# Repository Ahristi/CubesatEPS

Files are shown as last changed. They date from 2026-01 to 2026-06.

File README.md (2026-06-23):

# CubeSat EPS

Electrical Power System (EPS) hardware and firmware for a Docker-1 Cubesat. The project contains Altium projects and embedded firmware for the two EPS PCBs: The Battery Management System (BMS) and the Power Distribution Module (PDM).
<table>
  <tr>
    <td align="center">
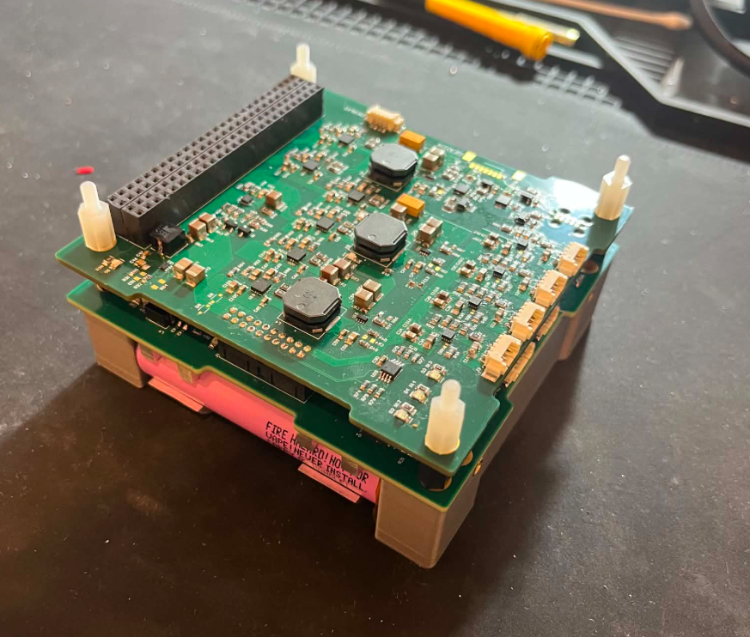
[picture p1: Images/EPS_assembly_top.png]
EPS Assembly top view
      <br>
      <b>EPS Assembly top view</b>
    </td>
    <td align="center">
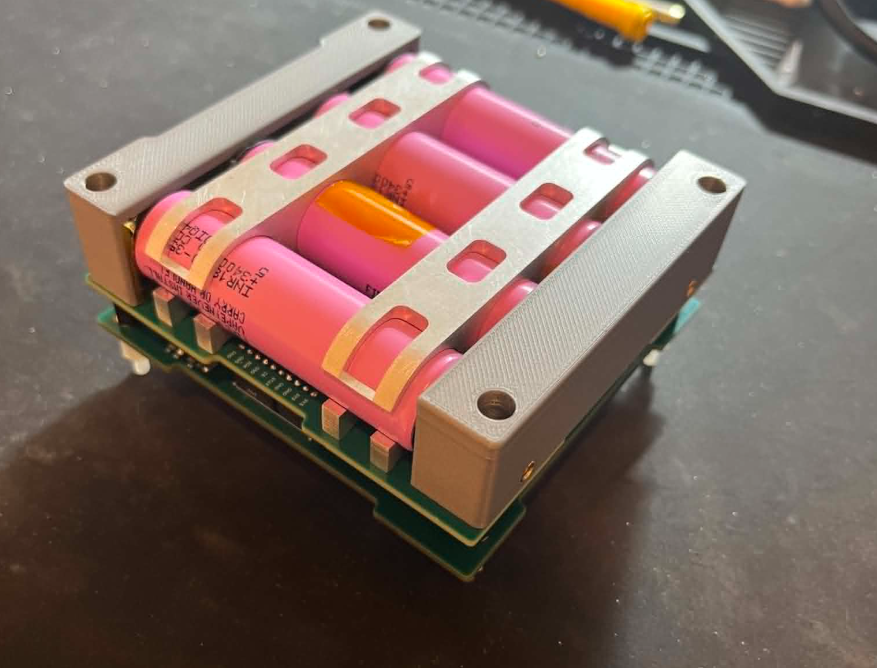
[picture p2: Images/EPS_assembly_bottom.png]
EPS Assembly bottom view
      <br>
      <b>EPS Assembly bottom view</b>
    </td>
  </tr>
</table>

## Overview
The EPS is comprised of two boards:
- **BMS — Battery Management System**: Contains a 4S Li-Ion battery directly soldered to the PCB. Performs battery protection, battery seperation, umbilical charging and solar panel charging via two MPPT boost circuits.
<table>
  <tr>
    <td align="center">
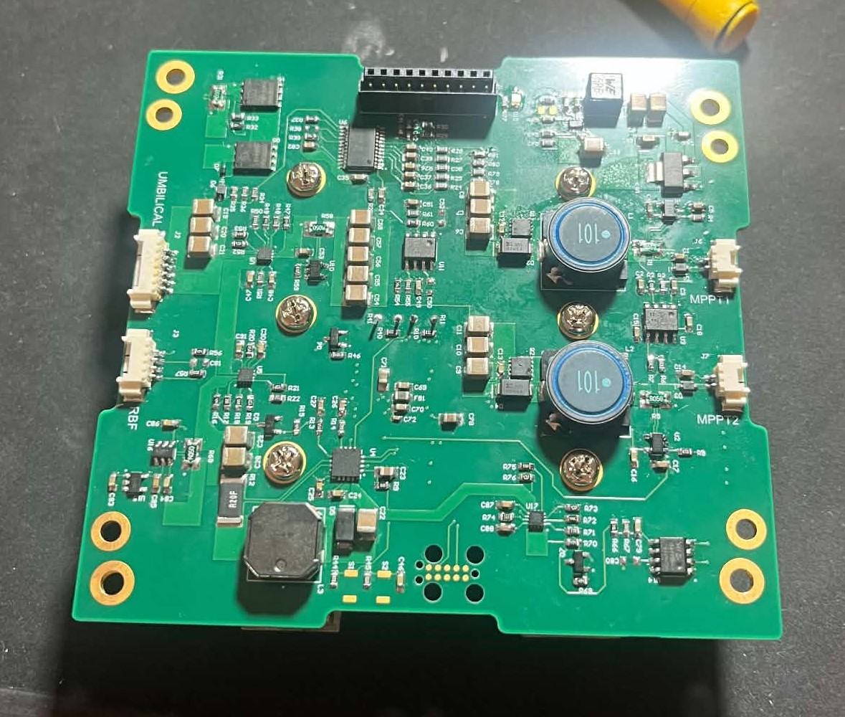
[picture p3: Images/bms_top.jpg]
BMS PCB top view
      <br>
      <b>BMS PCB</b>
    </td>
    <td align="center">
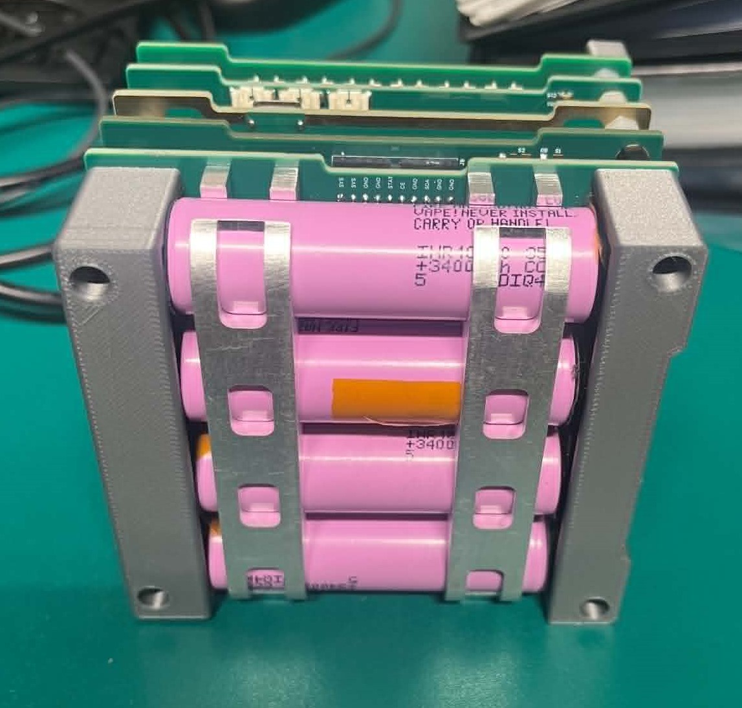
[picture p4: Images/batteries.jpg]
Bottom of BMS showing battery mounting
      <br>
      <b>Battery Pack</b>
    </td>
  </tr>
</table>

- **PDM — Power Distribution Module**: Regulates the raw battery voltage from the BMS to the voltages required by other subsystems on the satellite.
<table>
  <tr>
    <td align="center">
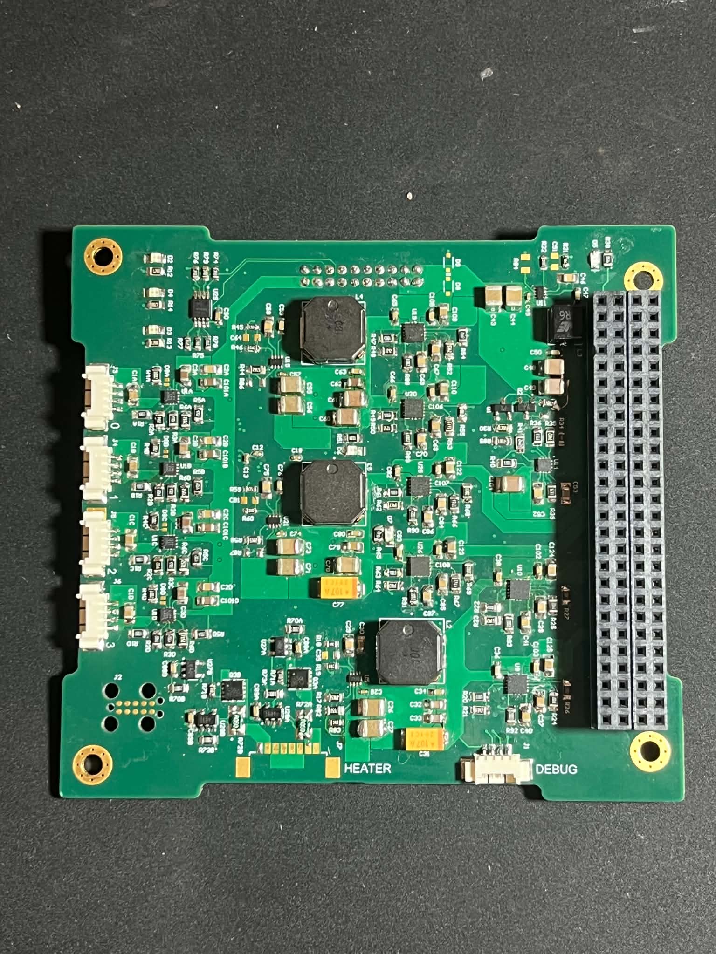
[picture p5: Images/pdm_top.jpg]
PDM PCB top view
      <br>
      <b>BMS PCB</b>
    </td>
    <td align="center">
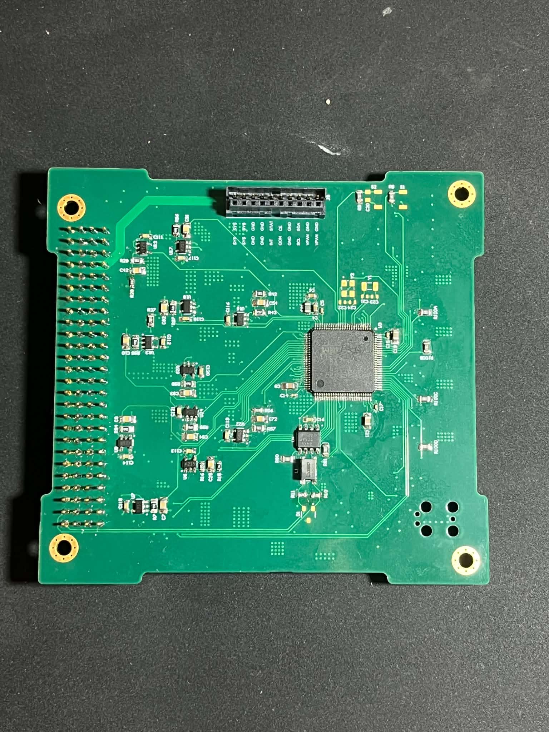
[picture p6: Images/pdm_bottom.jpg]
PDM PCB bottom view
      <br>
      <b>Battery Pack</b>
    </td>
  </tr>
</table>

The firmware for the PDM is an STM32 eclipse project. With code generated using HAL libraries from CubeMX. The firmware for the BMS is a platformIO project, with code also generated from STM32CubeMX

## Repository Structure

```text
CubesatEPS/
├── CAD/                  # Mechanical/CAD assets
├── Software/             # Firmware and Python support tools
│   ├── BMS/              # STM32 BMS firmware project
│   ├── BMS_Test/         # BMS test firmware/software
│   ├── PDM/              # PDM firmware, CAN tools, telemetry scripts
│       ├──  PDM/         # STM32 project for PDM
|       └──  EPS_gui.py   # Python script used to monitor EPS CAN telemetry and turn eFuses on/off.
├── hardware/             # PCB design files
│   ├── BMS/              # BMS Altium hardware project files
│   └── PDM/              # PDM Altium hardware project files
└── .gitignore
```

## Main Features

### Battery Management System

- Battery protection and power-path control
- Solar input regulation and MPPT control
- Umbilical charging interface
- ADC-based telemetry acquisition
- STM32Cube/PlatformIO firmware project
- ST-Link upload and debug support

### Power Distribution Module

- Regulated spacecraft power rails
- Protected load switching/eFuse control
- Voltage and current telemetry
- CAN-based command and telemetry interface
- Python tools for listening to, decoding, and plotting EPS telemetry

### Software Tooling

- STM32Cube-generated firmware structure
- PlatformIO build support for the BMS firmware
- Python CAN controller/listener utilities
- JSON-based command and conversion definitions
- Live plotting scripts for power rail current testing

## Hardware

The hardware design files are stored under:

```text
hardware/BMS/
hardware/PDM/
```

These folders contain the Altium projects for battery management and power distribution boards.
## Known Issues
- Battery current measurement is a quite poor. This is because the current measurement instrumentation amplifier is backfeeding current to the 1.5V reference which causes the reference to rise to about 2.4V. This needs to be fixed by adding a lower output impedance bbuffer ont he output of the LDO.
- PDM 6V enable MOSFET circuit is incorrect. R33 should be pulled directly to 5V5. This was fixed by a small rework on the board, but should be fixed in the next revision.
- Legacy GPIOs on the mezzanine connector which do nothing currently. This were to ensure backwards compatibility with old V1 hardware but aren't used anymore.
- Heater driver is currently untested as we didn't use it in the end for the DOCKER-1 project.

## Future improvements
- I2C is a bit finnicky for the PDM to BMS link. In a future revision I would probably change it to be directly on the CANbus.
- Ideal diodes on the PDM are legacy hardware that are unused as MPPT is done directly on the BMS. Previously on the V1 of the BMS, the BMS contained a single MPPT circuit and these ideal diodes would output whichever panel was the most illuminated.
- Change the buck converter ICs from TPS6993 to AP64501. I was planning on doing this in a second revision of the PDM but unfortunately ran out of time since I had 5 other PCBs to design for the satellite.
- If you have to do one thing I beg you to replace all the PDM efuses with TPS25497. The TPS16410 that I used for all the PDM outputs (except for the 6V output) is a piece of shit and really hard to solder. The TPS25947 is marginally more expensive, but has a higher current rating and reverse current blocking. We had some issues plugging USBs into boards downstream using the TPS16410. The TPS25947 is much easier to solder as well from my experience.

## Author

Developed by Tom Holland / Ahristi as part of the DOCKER-1 project for AERO4701 at the University of Sydney

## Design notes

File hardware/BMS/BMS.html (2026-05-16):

Altium customize

# Board Information Report

Date: | | 16/05/2026
Time: | | 10:33:02 AM
Elapsed Time: | | 00:00:00
Filename: | | C:\Users\Tom\Documents\CubesatEPS\hardware\BMS\BMS.PcbDoc

## Contents

Contents

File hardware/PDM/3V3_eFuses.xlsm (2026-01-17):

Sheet: TPS1641x_Calculation Sheet
TPS1641x Design Calculation Tool |  |  |  |  |  |  |  |  | Table - 1: Device Comparison Table
Constants Cells | Input/SelectCells | Calculation Cells |  |  | Recommended |  |  |  | TPS16410 | PLIM | Auto-Retry
Error Cells, Must be Fixed | Calculated, but can be over-ridden by user |  |  |  | Value |  |  |  | TPS16411 | PLIM | Latch-Off
Parameter | Description | Value | Units | Tolerance |  |  |  |  | TPS16412 | ILIM | Auto-Retry
Device Selection | Refer Table-1 and select device based on current or power limiting requirement and fault behavior (auto-retry or latchoff) | TPS16416 |  |  |  |  |  |  | TPS16413 | ILIM | Latch-Off
VIN (nom) | Nominal operating input voltage | 3.30 | V |  |  |  |  |  | TPS16414 | PLIM | Auto-Retry
Cout | Load Capacitance | 100.00 | uF | 10.0% |  |  |  |  | TPS16415 | PLIM | Latch-Off
Iout | Maximum load current | 0.50 | A |  |  |  |  |  | TPS16416 | ILIM | Auto-Retry
Icharge_req | Charging (inrush) current desired in the system | 0.20 | A |  |  |  |  |  | TPS16417 | ILIM | Latch-Off
ILIM | Current limit threshold for active current limiting | 0.70 | A
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

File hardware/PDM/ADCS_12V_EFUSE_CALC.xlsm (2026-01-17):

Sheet: TPS1641x_Calculation Sheet
TPS1641x Design Calculation Tool |  |  |  |  |  |  |  |  | Table - 1: Device Comparison Table
Constants Cells | Input/SelectCells | Calculation Cells |  |  | Recommended |  |  |  | TPS16410 | PLIM | Auto-Retry
Error Cells, Must be Fixed | Calculated, but can be over-ridden by user |  |  |  | Value |  |  |  | TPS16411 | PLIM | Latch-Off
Parameter | Description | Value | Units | Tolerance |  |  |  |  | TPS16412 | ILIM | Auto-Retry
Device Selection | Refer Table-1 and select device based on current or power limiting requirement and fault behavior (auto-retry or latchoff) | TPS16416 |  |  |  |  |  |  | TPS16413 | ILIM | Latch-Off
VIN (nom) | Nominal operating input voltage | 12.00 | V |  |  |  |  |  | TPS16414 | PLIM | Auto-Retry
Cout | Load Capacitance | 100.00 | uF | 10.0% |  |  |  |  | TPS16415 | PLIM | Latch-Off
Iout | Maximum load current | 1.40 | A |  |  |  |  |  | TPS16416 | ILIM | Auto-Retry
Icharge_req | Charging (inrush) current desired in the system | 0.20 | A |  |  |  |  |  | TPS16417 | ILIM | Latch-Off
ILIM | Current limit threshold for active current limiting | 1.60 | A
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

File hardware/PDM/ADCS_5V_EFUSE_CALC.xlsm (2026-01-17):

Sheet: TPS1641x_Calculation Sheet
TPS1641x Design Calculation Tool |  |  |  |  |  |  |  |  | Table - 1: Device Comparison Table
Constants Cells | Input/SelectCells | Calculation Cells |  |  | Recommended |  |  |  | TPS16410 | PLIM | Auto-Retry
Error Cells, Must be Fixed | Calculated, but can be over-ridden by user |  |  |  | Value |  |  |  | TPS16411 | PLIM | Latch-Off
Parameter | Description | Value | Units | Tolerance |  |  |  |  | TPS16412 | ILIM | Auto-Retry
Device Selection | Refer Table-1 and select device based on current or power limiting requirement and fault behavior (auto-retry or latchoff) | TPS16416 |  |  |  |  |  |  | TPS16413 | ILIM | Latch-Off
VIN (nom) | Nominal operating input voltage | 5.00 | V |  |  |  |  |  | TPS16414 | PLIM | Auto-Retry
Cout | Load Capacitance | 100.00 | uF | 10.0% |  |  |  |  | TPS16415 | PLIM | Latch-Off
Iout | Maximum load current | 0.50 | A |  |  |  |  |  | TPS16416 | ILIM | Auto-Retry
Icharge_req | Charging (inrush) current desired in the system | 0.20 | A |  |  |  |  |  | TPS16417 | ILIM | Latch-Off
ILIM | Current limit threshold for active current limiting | 1.00 | A
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

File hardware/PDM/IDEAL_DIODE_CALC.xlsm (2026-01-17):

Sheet: Calculation Sheet
LM73100 Design Calculation Tool
 | Constants Cells
 | Input/SelectCells
 | Calculation Cells
 | Calculated, but can be over-ridden by user
 | Error Cells, Must be Fixed
Parameter | Description | Value | Units | Tolerance | Recommended Value
VIN (max) | Maximum Operating input voltage (magnitude) | 8.00 | V
OVLO Set Point | Desired Over Voltage Lockout Set Point | 9.00 | V | 3.0%
UVLO Set Point | Desired Undervoltage Threshold (VIN Rising) | 2.00 | V | 3.0%
VUVP | Internal Undervoltage Protection Threshold (VIN Rising) | 2.53 | V | 3.0%
Cout | Load Capacitance | 470.0 | uF | 10.0%
Rlstart | Load at startup | 100.0 | Ohm |  | 16.0
Load turn on voltage | Output voltage at which startup load will start drawing current | 0 | V
Imax | Maximum continuous load current (magnitude) | 0.50 | A
TA, MAX | Maximum Operating Ambient temperature | 25.00 | °C
UVLO, OVLO set point calculations |  |  |  |  |  |  |  |  | R2+R3
UVLO Set Point | Desired Undervoltage Threshold (VIN Rising) | 2.00 |  |  |  |  |  |  | 705
OVLO Set Point | Desired Over Voltage Lockout Set Point | 9.00 |  |  |  |  | 1.83 | Power Fail (VIN Falling) | R2
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

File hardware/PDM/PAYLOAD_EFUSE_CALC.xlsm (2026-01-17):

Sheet: TPS1641x_Calculation Sheet
TPS1641x Design Calculation Tool |  |  |  |  |  |  |  |  | Table - 1: Device Comparison Table
Constants Cells | Input/SelectCells | Calculation Cells |  |  | Recommended |  |  |  | TPS16410 | PLIM | Auto-Retry
Error Cells, Must be Fixed | Calculated, but can be over-ridden by user |  |  |  | Value |  |  |  | TPS16411 | PLIM | Latch-Off
Parameter | Description | Value | Units | Tolerance |  |  |  |  | TPS16412 | ILIM | Auto-Retry
Device Selection | Refer Table-1 and select device based on current or power limiting requirement and fault behavior (auto-retry or latchoff) | TPS16416 |  |  |  |  |  |  | TPS16413 | ILIM | Latch-Off
VIN (nom) | Nominal operating input voltage | 12.00 | V |  |  |  |  |  | TPS16414 | PLIM | Auto-Retry
Cout | Load Capacitance | 100.00 | uF | 10.0% |  |  |  |  | TPS16415 | PLIM | Latch-Off
Iout | Maximum load current | 0.40 | A |  |  |  |  |  | TPS16416 | ILIM | Auto-Retry
Icharge_req | Charging (inrush) current desired in the system | 0.20 | A |  |  |  |  |  | TPS16417 | ILIM | Latch-Off
ILIM | Current limit threshold for active current limiting | 0.50 | A
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

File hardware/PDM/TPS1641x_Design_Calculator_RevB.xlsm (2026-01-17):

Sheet: TPS1641x_Calculation Sheet
TPS1641x Design Calculation Tool |  |  |  |  |  |  |  |  | Table - 1: Device Comparison Table
Constants Cells | Input/SelectCells | Calculation Cells |  |  | Recommended |  |  |  | TPS16410 | PLIM | Auto-Retry
Error Cells, Must be Fixed | Calculated, but can be over-ridden by user |  |  |  | Value |  |  |  | TPS16411 | PLIM | Latch-Off
Parameter | Description | Value | Units | Tolerance |  |  |  |  | TPS16412 | ILIM | Auto-Retry
Device Selection | Refer Table-1 and select device based on current or power limiting requirement and fault behavior (auto-retry or latchoff) | TPS16416 |  |  |  |  |  |  | TPS16413 | ILIM | Latch-Off
VIN (nom) | Nominal operating input voltage | 3.30 | V |  |  |  |  |  | TPS16414 | PLIM | Auto-Retry
Cout | Load Capacitance | 100.00 | uF | 10.0% |  |  |  |  | TPS16415 | PLIM | Latch-Off
Iout | Maximum load current | 0.50 | A |  |  |  |  |  | TPS16416 | ILIM | Auto-Retry
Icharge_req | Charging (inrush) current desired in the system | 0.20 | A |  |  |  |  |  | TPS16417 | ILIM | Latch-Off
ILIM | Current limit threshold for active current limiting | 0.70 | A
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

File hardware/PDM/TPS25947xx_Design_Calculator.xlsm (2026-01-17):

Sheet: Calculation Sheet
TPS25947xx Design Calculation Tool
 |  |  |  |  |  |  |  |  |  | Table - 1: Device Comparison Table
 | Constants Cells |  |  |  |  |  |  |  |  | Part number | Overvoltage Response | Overcurrent response | AUXOFF or PG | FLT or PGTH | Response to Thermal Shutdown (TSD) |  | 3.8 | 5.7 | 13.8
 | Input/SelectCells |  |  |  |  |  |  |  |  | TPS259470A | Adjustable OVLO | Active Current Limit | AUXOFF | FLT | Auto-Retry |  | Short | Open | 390
 | Calculation Cells |  |  |  |  |  |  |  |  | TPS259470L | Adjustable OVLO | Active Current Limit | AUXOFF | FLT | Latch-off
 | Calculated, but can be over-ridden by user |  |  |  |  |  |  |  |  | TPS259472A | Pin Selectable OVC (3.8 V/5.7 V/13.8 V) | Active Current Limit | PG | PGTH | Auto-Retry
 | Error Cells, Must be Fixed |  |  |  |  |  |  |  |  | TPS259472L | Pin Selectable OVC(3.8 V/5.7 V/13.8 V) | Active Current Limit | PG | PGTH | Latch-off
 |  |  |  |  |  |  |  |  |  | TPS259474A | Adjustable OVLO | Circuit Breaker | PG | PGTH | Auto-retry
Parameter | Description | Value | Units | Tolerance | Recommended Value |  |  |  |  | TPS259474L | Adjustable OVLO | Circuit Breaker | PG | PGTH | Latch-off
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

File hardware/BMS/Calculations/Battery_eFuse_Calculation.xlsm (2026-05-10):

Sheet: Calculation Sheet
TPS25947xx Design Calculation Tool
 |  |  |  |  |  |  |  |  |  | Table - 1: Device Comparison Table
 | Constants Cells |  |  |  |  |  |  |  |  | Part number | Overvoltage Response | Overcurrent response | AUXOFF or PG | FLT or PGTH | Response to Thermal Shutdown (TSD) |  | 3.8 | 5.7 | 13.8
 | Input/SelectCells |  |  |  |  |  |  |  |  | TPS259470A | Adjustable OVLO | Active Current Limit | AUXOFF | FLT | Auto-Retry |  | Short | Open | 390
 | Calculation Cells |  |  |  |  |  |  |  |  | TPS259470L | Adjustable OVLO | Active Current Limit | AUXOFF | FLT | Latch-off
 | Calculated, but can be over-ridden by user |  |  |  |  |  |  |  |  | TPS259472A | Pin Selectable OVC (3.8 V/5.7 V/13.8 V) | Active Current Limit | PG | PGTH | Auto-Retry
 | Error Cells, Must be Fixed |  |  |  |  |  |  |  |  | TPS259472L | Pin Selectable OVC(3.8 V/5.7 V/13.8 V) | Active Current Limit | PG | PGTH | Latch-off
 |  |  |  |  |  |  |  |  |  | TPS259474A | Adjustable OVLO | Circuit Breaker | PG | PGTH | Auto-retry
Parameter | Description | Value | Units | Tolerance | Recommended Value |  |  |  |  | TPS259474L | Adjustable OVLO | Circuit Breaker | PG | PGTH | Latch-off
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

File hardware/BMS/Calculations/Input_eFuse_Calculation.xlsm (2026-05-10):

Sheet: Calculation Sheet
TPS25947xx Design Calculation Tool
 |  |  |  |  |  |  |  |  |  | Table - 1: Device Comparison Table
 | Constants Cells |  |  |  |  |  |  |  |  | Part number | Overvoltage Response | Overcurrent response | AUXOFF or PG | FLT or PGTH | Response to Thermal Shutdown (TSD) |  | 3.8 | 5.7 | 13.8
 | Input/SelectCells |  |  |  |  |  |  |  |  | TPS259470A | Adjustable OVLO | Active Current Limit | AUXOFF | FLT | Auto-Retry |  | Short | Open | 390
 | Calculation Cells |  |  |  |  |  |  |  |  | TPS259470L | Adjustable OVLO | Active Current Limit | AUXOFF | FLT | Latch-off
 | Calculated, but can be over-ridden by user |  |  |  |  |  |  |  |  | TPS259472A | Pin Selectable OVC (3.8 V/5.7 V/13.8 V) | Active Current Limit | PG | PGTH | Auto-Retry
 | Error Cells, Must be Fixed |  |  |  |  |  |  |  |  | TPS259472L | Pin Selectable OVC(3.8 V/5.7 V/13.8 V) | Active Current Limit | PG | PGTH | Latch-off
 |  |  |  |  |  |  |  |  |  | TPS259474A | Adjustable OVLO | Circuit Breaker | PG | PGTH | Auto-retry
Parameter | Description | Value | Units | Tolerance | Recommended Value |  |  |  |  | TPS259474L | Adjustable OVLO | Circuit Breaker | PG | PGTH | Latch-off
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

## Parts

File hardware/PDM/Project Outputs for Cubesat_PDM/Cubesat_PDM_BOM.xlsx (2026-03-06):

Line # | Designator | Name | Distributor Part Number | Description | Quantity
 | C1A, C1B, C1C, C1D, C109, C110, C122, C123, C124, C125 | CL21B105KAFNNNE | 1276-1066-1-ND | 1uF ±10% 25V Ceramic Capacitor X7R 0805 (2012 Metric) | 20
 | C2A, C2B, C2C, C2D, C25, C42, C54, C72 | CL21B104KACNNNC | 1276-1099-1-ND | 0.1uF ±10% 25V Ceramic Capacitor X7R 0805 (2012 Metric) | 20
 | C3A, C3B, C3C, C3D, C7, C8, C10, C29, C40, C41, C46, C58, C69, C70, C75, C91, C92, C93, C94 | CL21B103KBANNNC | 1276-1015-1-ND | 10nF ±10% 50V Ceramic Capacitor X7R 0805 (2012 Metric) | 30
 | C4, C6 | CL10B105KO8NNNC | 1276-1019-1-ND | 1 µF ±10% 16V Ceramic Capacitor X7R 0603 (1608 Metric) | 10
 | C5, C12, C13, C14, C15, C17, C18, C28, C45, C57, C74 | CL05B104KB5NNNC | 1276-CL05B104KB5NNNCCT-ND | 0.1 µF ±10% 50V Ceramic Capacitor X7R 0402 (1005 Metric) | 20
 | C9, C11 | CL21A225KBFNNNE | 1276-6702-1-ND | 2.2uF ±10% 25V Ceramic Capacitor X7R 0805 (2012 Metric) | 10
 | C19 | CL21B475KOFNFNE | 1276-2970-1-ND | 4.7 µF ±10% 16V Ceramic Capacitor X7R 0805 (2012 Metric) | 10
 | C21, C23 | KGM05ACG1H180FH | 478-KGM05ACG1H180FHCT-ND | 18 pF ±1% 50V Ceramic Capacitor C0G, NP0 0402 (1005 Metric) | 10
 | C22, C24 | GJM1555C1H140FB01D | 2266-GJM1555C1H140FB01DTR-ND | 14 pF ±1% 50V Ceramic Capacitor C0G, NP0 0402 (1005 Metric) | 10
 | C26, C27, C43, C44, C55, C56, C71, C73 | CL32B106KBJNNNE | 1276-3387-1-ND | 10 µF ±10% 50V Ceramic Capacitor X7R 1210 (3225 Metric) | 20
 | C31, C77 | TPSC107K010R0100 | 478-1765-1-ND | 100 µF Molded Tantalum Capacitors 10 V 2312 (6032 Metric) 100mOhm | 4
 | C32, C33 | GRM21BZ71A226ME15L | 490-GRM21BZ71A226ME15LCT-ND | 22 µF ±20% 10V Ceramic Capacitor X7R 0805 (2012 Metric) | 10
 | C35, C51, C64, C81 | C0603C104K5RACTU | 399-C0603C100J5GACTUCT-ND | 10 pF ±5% 50V Ceramic Capacitor C0G, NP0 0603 (1608 Metric) | 10
 | C37, C39, C67, C68, C84, C85 | CL21B473KBCNNNC | 1276-1250-1-ND | 0.047 µF ±10% 50V Ceramic Capacitor X7R 0805 (2012 Metric) | 10
 | C48, C49, C60, C61, C78 | CL32B226KAJNNNE | 1276-3392-1-ND | 22 µF ±10% 25V Ceramic Capacitor X7R 1210 (3225 Metric) | 10
 | C52, C86, C87 | CL21B105KAFNNNE | 1276-1155-1-ND | 4.7nF ±10% 50V Ceramic Capacitor X7R 0805 (2012 Metric) | 10
 | C53 | GRM2165C1H272JA01D | 490-1630-1-ND | 2.7nF ±5% 50V Ceramic Capacitor C0G, NP0 0805 (2012 Metric) | 10
 | C62, C79 | CL21B105KBFNNNE | 1276-1029-1-ND | 1uF 50V X7R ±10% 0805 Multilayer Ceramic Capacitors MLCC - SMD/SMT ROHS | 10
 | C101A, C101B, C101C, C101D | GRM21BZ71E106KE15L | 490-GRM21BZ71E106KE15LCT-ND | 10uF ±10% 25V Ceramic Capacitor X7R 0805 (2012 Metric) | 10
 | C104 | CL32B226MOJNNNE | 1276-3395-1-ND | 22 µF ±20% 16V Ceramic Capacitor X7R 1210 (3225 Metric) | 10
 | D2 | LTST-C170EKT | 160-1178-1-ND | Red 621nm LED Indication - Discrete 2V 0805 (2012 Metric) | 5
 | D3, D4 | LTST-C170GKT | 160-1179-1-ND | Green 569nm LED Indication - Discrete 2.1V 0805 (2012 Metric) | 5
 | D5, D6, D7 | LSM0805463V | 28-LSM0805463VCT-ND | Blue 469nm LED Indication - Discrete 3V 0805 (2012 Metric) | 5
 | FB1 | 74279220321 | 732-6125-1-ND | Ferrite Bead 320 Ohms @ 100 MHz 1 Ferrite Bead 0805 (2012 Metric) 2.5A 50mOhm | 5
 | J1, J3, J4, J5, J6 | 0532610471 | WM7622CT-ND | Connector Header Surface Mount, Right Angle 4 position 0.049" (1.25mm) Molex Picoblade | 6
 | J7 | 0532610871 | WM7624CT-ND | Connector Header Surface Mount, Right Angle 8 position 0.049" (1.25mm) Picoblade | 2
 | L1 | ACT45B-101-2P-TL003 | 445-3959-1-ND | Common Mode Choke 100 µH @ 100 kHz 2 Line Surface Mount 5.8 kOhms @ 10 MHz 150mA DCR 2Ohm | 2
 | L2, L4, L5 | 1274AS-H-100M=P3 | 490-10846-1-ND | Inductor 10 µH , 4.4 A 30.4mOhm Max Shielded Drum Core | 4
 | L3 | 744316560 | 732-6183-1-ND | Inductor 5.6uH 4.5A Shielded 28.5mOhm SMD | 2
 | Q1, Q2 | T2N7002AK,LM | T2N7002AKLMCT-ND | N-Channel 60 V 200mA (Ta) 320mW (Ta) Surface Mount SOT-23-3 | 10
 | Q3A, Q3B | NTTFS5C454NLTAG | NTTFS5C454NLTAGOSCT-ND | N-MOSFET 40 V , 85 A, 3.8 mΩ Rds(on) @ 10 V, WDFN-8 3.3×3.3 mm, low Qg (~18 nC) | 4
 | R1A, R1B, R1C, R1D, R20, R22, R37, R40, R47, R49, R61, R63, R100A, R100B, R100C, R100D | RMCF0805FG100K | RMCF0805FG100KCT-ND | 100 kOhms ±1% 0.125W, 1/8W Chip Resistor 0805 (2012 Metric) Automotive AEC-Q200 Thick Film | 20
 | R2A, R2B, R2C, R2D, R24, R25 | RMCF0805FT14K0 | RMCF0805FT14K0CT-ND | 14 kOhms ±1% 0.125W, 1/8W Chip Resistor 0805 (2012 Metric) Automotive AEC-Q200 Thick Film | 10
 | R3A, R3B, R3C, R3D, R5A, R5B, R5C, R5D, R43 | RMCF0805FT47K0 | RMCF0805FT47K0CT-ND | 47 kOhms ±1% 0.125W, 1/8W Chip Resistor 0805 (2012 Metric) Automotive AEC-Q200 Thick Film | 20
 | R4A, R4B, R4C, R4D, R8, R9, R33, R70A, R70B, R73A, R73B, R84, R85, R86, R87, R88, R89, R90, R91, R92, R93 | RMCF0805FT10K0 | RMCF0805FT10K0CT-ND | 10 kOhms ±1% 0.125W, 1/8W Chip Resistor 0805 (2012 Metric) Automotive AEC-Q200 Thick Film | 30
 | R6A, R6B, R6C, R6D, R82 | RMCF0805FT71K5 | RMCF0805FT71K5CT-ND | 71.5 kOhms ±1% 0.125W, 1/8W Chip Resistor 0805 (2012 Metric) Automotive AEC-Q200 Thick Film | 10
 | R7, R94, R95, R96, R97, R98, R99 | RMCF0805FT499R | RMCF0805FT499RCT-ND | 499 Ohms ±1% 0.125W, 1/8W Chip Resistor 0805 (2012 Metric) Automotive AEC-Q200 Thick Film | 10
 | R10, R11 | RMCF0603FT1K20 | RMCF0603FT1K20CT-ND | 1.2 kOhms ±1% 0.1W, 1/10W Chip Resistor 0603 (1608 Metric) Automotive AEC-Q200 Thick Film | 10
 | R12, R13, R14, R38, R65 | RMCF0805FT120R | 738-RMCF0805FT120RCT-ND | 120 Ohms ±1% 0.125W, 1/8W Chip Resistor 0805 (2012 Metric) Automotive AEC-Q200 Thick Film | 10
 | R15 | RMCF0603FT93K1 | RMCF0603FT93K1CT-ND | 93.1 kOhms ±1% 0.1W, 1/10W Chip Resistor 0603 (1608 Metric) Automotive AEC-Q200 Thick Film | 10
 | R16 | RMCF0603FT100K | RMCF0603FT100KCT-ND | 100 kOhms ±1% 0.1W, 1/10W Chip Resistor 0603 (1608 Metric) Automotive AEC-Q200 Thick Film | 10
 | R17, R44, R58 | RMCF0805FT53K6 | RMCF0805FT53K6CT-ND | 53.6 kOhms ±1% 0.125W, 1/8W Chip Resistor 0805 (2012 Metric) Automotive AEC-Q200 Thick Film | 10
 | R18 | RMCF0603FT31K6 | RMCF0603FT31K6CT-ND | 31.6 kOhms ±1% 0.1W, 1/10W Chip Resistor 0603 (1608 Metric) Automotive AEC-Q200 Thick Film | 10
 | R19, R32, R46, R60, R74, R75, R76, R77, R78, R79, R83 | RMCF0603FT10K0 | RMCF0603FT10K0CT-ND | 10 kOhms ±1% 0.1W, 1/10W Chip Resistor 0603 (1608 Metric) Automotive AEC-Q200 Thick Film | 20
 | R21, R23 | RMCF0805FT63K4 | RMCF0805FT63K4CT-ND | 63.4 kOhms ±1% 0.125W, 1/8W Chip Resistor 0805 (2012 Metric) Automotive AEC-Q200 Thick Film | 10
 | R26, R27 | RMCF0805FT18K0 | RMCF0805FT18K0CT-ND | 18 kOhms ±1% 0.125W, 1/8W Chip Resistor 0805 (2012 Metric) Automotive AEC-Q200 Thick Film | 10
 | R28, R56 | RMCF0603FT174K | RMCF0603FT174KCT-ND | 174 kOhms ±1% 0.1W, 1/10W Chip Resistor 0603 (1608 Metric) Automotive AEC-Q200 Thick Film | 10
 | R29, R42, R57 | RMCF0805FT332K | RMCF0805FT332KCT-ND | 332 kOhms ±1% 0.125W, 1/8W Chip Resistor 0805 (2012 Metric) Automotive AEC-Q200 Thick Film | 10
 | R30 | RMCF0805FT100R | RMCF0805FT100RCT-ND | 100 Ohms ±1% 0.125W, 1/8W Chip Resistor 0805 (2012 Metric) Automotive AEC-Q200 Thick Film | 10
 | R31 | RMCF0603FT59K0 | RMCF0603FT59K0CT-ND | 59 kOhms ±1% 0.1W, 1/10W Chip Resistor 0603 (1608 Metric) Automotive AEC-Q200 Thick Film | 10
 | R34 | RMCF0603FT470K | RMCF0603FT470KCT-ND | 470 kOhms ±1% 0.1W, 1/10W Chip Resistor 0603 (1608 Metric) Automotive AEC-Q200 Thick Film | 10
 | R35, R62, R64 | RMCF0805FT34K8 | RMCF0805FT34K8CT-ND | 34.8 kOhms ±1% 0.125W, 1/8W Chip Resistor 0805 (2012 Metric) Automotive AEC-Q200 Thick Film | 10
 | R36 | RMCF0805FT115K | RMCF0805FT115KCT-ND | 115 kOhms ±1% 0.125W, 1/8W Chip Resistor 0805 (2012 Metric) Automotive AEC-Q200 Thick Film | 10
 | R39 | RMCF0805FT1K21 | RMCF0805FT1K21CT-ND | 1.21 kOhms ±1% 0.125W, 1/8W Chip Resistor 0805 (2012 Metric) Automotive AEC-Q200 Thick Film | 10
 | R41 | RMCF0805FT29K4 | RMCF0805FT29K4CT-ND | 29.4 kOhms ±1% 0.125W, 1/8W Chip Resistor 0805 (2012 Metric) Automotive AEC-Q200 Thick Film | 10
 | R45 | RMCF0603FT140K | RMCF0603FT140KCT-ND | 140 kOhms ±1% 0.1W, 1/10W Chip Resistor 0603 (1608 Metric) Automotive AEC-Q200 Thick Film | 10
 | R48, R50 | RMCF0805FT12K4 | RMCF0805FT12K4CT-ND | 12.4 kOhms ±1% 0.125W, 1/8W Chip Resistor 0805 (2012 Metric) Automotive AEC-Q200 Thick Film | 10
 | R51 | RMCF0805FT270R | RMCF0805FT270RCT-ND | 270 Ohms ±1% 0.125W, 1/8W Chip Resistor 0805 (2012 Metric) Automotive AEC-Q200 Thick Film | 10
 | R52 | RMCF0805FT19K6 | RMCF0805FT19K6CT-ND | 19.6 kOhms ±1% 0.125W, 1/8W Chip Resistor 0805 (2012 Metric) Automotive AEC-Q200 Thick Film | 10
 | R53 | RMCF0805FT6K19 | RMCF0805FT6K19CT-ND | 6.19 kOhms ±1% 0.125W, 1/8W Chip Resistor 0805 (2012 Metric) Automotive AEC-Q200 Thick Film | 10
 | R54 | RMCF0805FT20K0 | RMCF0805FT20K0CT-ND | 20 kOhms ±1% 0.125W, 1/8W Chip Resistor 0805 (2012 Metric) Automotive AEC-Q200 Thick Film | 10
 | R55 | RMCF0805FT9K10 | 738-RMCF0805FT9K10CT-ND | 9.1 kOhms ±1% 0.125W, 1/8W Chip Resistor 0805 (2012 Metric) Automotive AEC-Q200 Thick Film | 10
 | R59 | RMCF0603FT52K3 | RMCF0603FT174KCT-ND | 52.3 kOhms ±1% 0.1W, 1/10W Chip Resistor 0603 (1608 Metric) Automotive AEC-Q200 Thick Film | 10
 | R66, R67 | RMCF0805FT9K76 | RMCF0805FT9K76CT-ND | 9.76 kOhms ±1% 0.125W, 1/8W Chip Resistor 0805 (2012 Metric) Automotive AEC-Q200 Thick Film | 10
 | R68, R69 | RMCF0805FT13K0 | RMCF0805FT13K0CT-ND | 13 kOhms ±1% 0.125W, 1/8W Chip Resistor 0805 (2012 Metric) Automotive AEC-Q200 Thick Film | 10
 | R71A, R71B | RNCF0603AKT10R0 | RNCF0603AKT10R0CT-ND | 10 Ohms ±0.05% 0.1W, 1/10W Chip Resistor 0603 (1608 Metric) Automotive AEC-Q200 Thin Film | 10
 | R72A, R72B | LVK12R050CER | 273-LVK12R050CERCT-ND | Resistor, Current Sense 50 mOhms ±0.25% 0.5W, Moisture Resistant Thick Film | 10
 | R80, R81 | RNCP0805FTD1K00 | RNCP0805FTD1K00CT-ND | 1 kOhms ±1% 0.25W, 1/4W Chip Resistor 0805 (2012 Metric) Anti-Sulfur Thin Film | 10
 | S1, S2 | B3U-1000P | SW1020CT-ND | Tactile Switch SPST-NO Top Actuated Surface Mount | 10
 | U1A, U1B, U1C, U1D | LM73100RPWR | 296-LM73100RPWRCT-ND | Ideal Diode 2.7 - 23 V, 5.5 A with Input Reverse Polarity and Overvoltage Protection | 5
 | U3 | STM32F427VGT7 | 497-16769-ND | ARM® Cortex®-M4 STM32F4 Microcontroller IC 32-Bit 180MHz 1MB (1M x 8) FLASH 100-LQFP (14x14) | 2
 | U4 | TCAN3414DR | 296-TCAN3414DRCT-ND | 3.3 V CAN-FD transceiver, CAN/CAN-FD up to 8 Mb/s, ±58 V bus-fault tolerant, SOIC-8 | 2
 | U5, U11, U15, U21 | TPS62933DRLR | 296-TPS62933DRLRCT-ND | Buck Switching Regulator IC Positive Adjustable 0.8V 1 Output 3A SOT-583 | 5
 | U6, U7, U8, U12, U13, U16, U17, U18, U22, U23, U24 | TSZ181ILT | 497-18084-1-ND | Operational Amplifier, General Purpose, 2.2V~5.5V | 11
 | U9, U10, U19, U20, U25, U26 | TPS16410DRCR | 296-TPS16410DRCRCT-ND | 2.7-V to 40-V 152-mΩ 1.8-A eFuse with output power limiting | 8
 | U14 | TPS259474LRPWR | 296-TPS259474LRPWRCT-ND | eFuse 5.5A, 2.7V~23V, 28mOhm, Reverse Current Blocking with Input Reverse Polarity Protection | 3
 | U27A, U27B | UCC27517AQDBVRQ1 | 296-41038-1-ND | Low-Side Gate Driver IC Inverting, Non-Inverting SOT-23-5 | 2
 | U28A, U28B | INA139NA/250 | INA139NA/250CT-ND | 40V Current Sense Amplifier 1 Circuit 8-MSOP | 2
 | U29 | TCA9511ADGKR | 296-TCA9511ADGKRCT-ND | Hot-swappable, bidirectional I²C/SMBus bus buffer, 1 V precharge, standard/fast I²C, clock stretching, arbitration, and powered-off high-impedance on bus pins. | 1
 | Y1 | CM7VT1A32.768KHZ125PF20PPMTBQAT3 | 2195-CM7VT1A32.768KHZ125PF20PPMTBQAT3CT-ND | CRYSTAL 32.7680KHZ 12.5PF SMD | 3
 | Y2 | 830069882 | 732-830069882CT-ND | Crystals 12.0 MHZ 18PF 20PPM 120OHM | 3

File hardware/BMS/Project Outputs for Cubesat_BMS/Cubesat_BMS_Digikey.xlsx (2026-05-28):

Name | Description | Footprint | Designator | Distributor Part Number | Distributor | Quantity
1274AS-H-100M=P3 | Inductor 10 µH , 4.4 A 30.4mOhm Max Shielded Drum Core | 1274AS-H-100M=P3 | L3 | 490-10846-1-ND | Digikey | 2
0532610271 | Connector Header, Picoblade Surface Mount, Right Angle 2 position 0.049" (1.25mm) | 0532610271 | J6, J7 | WM7620CT-ND | Digikey | 10
0532610471 | Connector Header Surface Mount, Right Angle 4 position 0.049" (1.25mm) Molex Picoblade | 0532610471 | J3 | WM7622CT-ND | Digikey | 10
0532610671 | Connector Header Surface Mount, Right Angle 6 position 0.049" (1.25mm) Picoblade | 0532610671 | J2 | WM7624CT-ND | Digikey | 10
744316560 | Inductor 5.6uH 4.5A Shielded 28.5mOhm SMD | 744316560 | L4 | 732-6183-1-ND | Digikey | 3
74279220321 | Ferrite Bead 320 Ohms @ 100 MHz 1 Ferrite Bead 0805 (2012 Metric) 2.5A 50mOhm | 74279220321 | FB1 | 732-6125-1-ND | Digikey | 10
ADPL40502AUJZ-1.5-R7 | Linear Voltage Regulator IC Positive Fixed 1.5V Output 200mA TSOT-23-5 | SOT23-5 IC | U15 | 505-ADPL40502AUJZ-1.5-R7CT-ND | Digikey | 10
B3U-1000P | Tactile Switch SPST-NO Top Actuated Surface Mount | B3U-1000P | S1, S2 | SW1020CT-ND | Digikey | 2
B340LA-13-F | Diode Schottky 40V 3A 450mV FVf Fast Recovery | DO-214 | D2, D4, D5 | B340LA-FDICT-ND | Digikey | 10
BAV20WS-7-F | Small Signal Switching Diode 150V 200mW | SOD-323 | D6 | BAV20WS-FDICT-ND | Digikey | 10
BQ7791500PWR | Battery Battery Protection IC Lithium Ion/Polymer 24-TSSOP | TSSOP-24 | U6 | 296-50995-1-ND | Digikey | 3
C0603C472K4RECAUTO | 4.7nF ±10% 16V Ceramic Capacitor X7R 0603 (1608 Metric) | CAPC0603X040 | C27, C31, C48, C88 | 399-17879-1-ND | Digikey | 50
CL05B104KB5NNNC | 0.1 µF ±10% 50V Ceramic Capacitor X7R 0402 (1005 Metric) | CAPC0402X020 | C41, C42, C43, C61, C72, C73, C74, C75, C76, C77 | 1276-CL05B104KB5NNNCCT-ND | Digikey | 50
CL10B103KB8NNNC | 10nF ±10% 50V Ceramic Capacitor X7R 0603 (1608 Metric) | CAPC0603X060 | C30, C47, C62, C87 | 1276-1009-1-ND | Digikey | 50
CL10B105KO8NNNC | 1 µF ±10% 16V Ceramic Capacitor X7R 0603 (1608 Metric) | CAPC0603X040 | C69, C70 | 1276-1019-1-ND | Digikey | 50
CL10B222KB8WPNC | 2.2nF ±10% 50V Ceramic Capacitor X7R 0603 (1608 Metric) | CAPC0603X060 | C26 | 1276-6530-1-ND | Digikey | 50
CL21A225KBFNNNE | 2.2uF ±10% 25V Ceramic Capacitor X7R 0805 (2012 Metric) | CAPC0805X060 | C23, C71 | 1276-6702-1-ND | Digikey | 50
CL21B475KOFNFNE | 4.7 µF ±10% 16V Ceramic Capacitor X7R 0805 (2012 Metric) | CAPC0805X060 | C68, C78 | 1276-2970-1-ND | Digikey | 20
CL32B106KBJNNNE | 10 µF ±10% 50V Ceramic Capacitor X7R 1210 (3225 Metric) | CAPC1210X090 | C19, C20, C21, C22, C28, C29, C54, C55, C56, C57, C58, C59 | 1276-3387-1-ND | Digikey | 20
CL32B226KAJNNNE | 22 µF ±10% 25V Ceramic Capacitor X7R 1210 (3225 Metric) | CAPC1210X090 | C6, C7, C8, C9, C10, C11, C64, C65 | 1276-3392-1-ND | Digikey | 20
GJM1555C1H140FB01D | 14 pF ±1% 50V Ceramic Capacitor C0G, NP0 0402 (1005 Metric) | CAPC0402X020 | C44, C45 | 2266-GJM1555C1H140FB01DTR-ND | Digikey | 20
INA139NA/250 | 40V Current Sense Amplifier 1 Circuit 8-MSOP | SOT23-5 IC | U1, U2, U10 | INA139NA/250CT-ND | Digikey | 10
INA181A3IDBVR | Current Sense Amplifier Bidirectional 100V/V | SOT23-6 IC | U16 | 296-47658-1-ND | Digikey | 5
LS2-110-01-L-D | Connector Self Mating 20 Position , Non-Gendered, Hermaphroditic Through Hole Gold | LS2-110-01-L-D | J1 | SAM9665-ND | Digikey | 2
LTST-C170EKT | Red 621nm LED Indication - Discrete 2V 0805 (2012 Metric) | LEDR_0805 | D8 | 160-1178-1-ND | Digikey | 10
LTST-C170GKT | Green 569nm LED Indication - Discrete 2.1V 0805 (2012 Metric) | LEDG_0805 | D9 | 160-1179-1-ND | Digikey | 10
LTST-C171KRKT | Red 631nm LED Indication - Discrete 2V 0805 (2012 Metric) | LEDR_0805 | D10 | 160-1427-1-ND | Digikey | 10
LVK12R010FER | 10 mOhms ±1% 0.5W, 1/2W Chip Resistor 1206 (3216 Metric) Anti-Corrosive, Current Sense, Moisture Resistant Thick Film | LVK12R050CER-2 | R31 | 273-LVK12R010FERCT-ND | Digikey | 5
MCP6007T-E/SN | Operational Amplifier general purpose, 2-Circuit 1.8V ~ 5.5V 1MHz | SOIC-8 | U3, U11, U14 | 150-MCP6007T-E/SNCT-ND | Digikey | 10
MP26124GR-Z | Charger IC Lithium Ion 24V Input, 2A, 600kHz, 4S Cell Switching | qfn-16 | U4 | 1589-1993-1-ND | Digikey | 4
RMCF0603FT1K2 | 1.2 kOhms ±1% 0.1W, 1/10W Chip Resistor 0603 (1608 Metric) Automotive AEC-Q200 Thick Film | RESC0603 | R51, R74 | RMCF0603FT1K20CT-ND | Digikey | 10
RMCF0603FT1M00 | 1 MOhms ±1% 0.1W, 1/10W Chip Resistor 0603 (1608 Metric) Automotive AEC-Q200 Thick Film | RESC0603 | R33, R35, R36 | RMCF0603FT1M00CT-ND | Digikey | 10
RMCF0603FT2K26 | 2.26 kOhms ±1% 0.1W, 1/10W Chip Resistor 0603 (1608 Metric) Automotive AEC-Q200 Thick Film | RESC0603 | R77 | RMCF0603FT2K26CT-ND | Digikey | 10
RMCF0603FT3K48 | 3.48 kOhms ±1% 0.1W, 1/10W Chip Resistor 0603 (1608 Metric) Automotive AEC-Q200 Thick Film | RESC0603 | R22, R53, R75 | RMCF0603FT3K48CT-ND | Digikey | 10
RMCF0603FT4K7 | 4.7 kOhms ±1% 0.1W, 1/10W Chip Resistor 0603 (1608 Metric) Automotive AEC-Q200 Thick Film | RESC0603 | R32, R82, R83 | RMCF0603FT4K70CT-ND | Digikey | 10
RMCF0603FT6K19 | 6.19 kOhms ±1% 0.1W, 1/10W Chip Resistor 0603 (1608 Metric) Automotive AEC-Q200 Thick Film | RESC0603 | R48, R71 | RMCF0603FT6K19CT-ND | Digikey | 10
RMCF0603FT10K0 | 10 kOhms ±1% 0.1W, 1/10W Chip Resistor 0603 (1608 Metric) Automotive AEC-Q200 Thick Film | RESC0603 | R3, R7, R10, R38, R40, R55, R61, R63, R65, R67, R78, R79, R80, R81 | RMCF0603FT10K0CT-ND | Digikey | 100
RMCF0603FT10R0 | 10 Ohms ±1% 0.1W, 1/10W Chip Resistor 0603 (1608 Metric) Automotive AEC-Q200 Thick Film | RESC0603 | R9 | RMCF0603FT10R0CT-ND | Digikey | 100
RMCF0603FT11K3 | 11.3 kOhms ±1% 0.1W, 1/10W Chip Resistor 0603 (1608 Metric) Automotive AEC-Q200 Thick Film | RESC0603 | R17 | RMCF0603FT11K3CT-ND | Digikey | 10
RMCF0603FT27K0 | 27 kOhms ±1% 0.1W, 1/10W Chip Resistor 0603 (1608 Metric) Automotive AEC-Q200 Thick Film | RESC0603 | R2, R6 | RMCF0603FT27K0CT-ND | Digikey | 10
RMCF0603FT28K0 | 28 kOhms ±1% 0.1W, 1/10W Chip Resistor 0603 (1608 Metric) Automotive AEC-Q200 Thick Film | RESC0603 | R49, R72 | RMCF0603FT28K0CT-ND | Digikey | 10
RMCF0603FT37K4 | 37.4 kOhms ±1% 0.1W, 1/10W Chip Resistor 0603 (1608 Metric) Automotive AEC-Q200 Thick Film | RESC0603 | R18 | RMCF0603FT37K4CT-ND | Digikey | 10
RMCF0603FT42K2 | 42.2 kOhms ±1% 0.1W, 1/10W Chip Resistor 0603 (1608 Metric) Automotive AEC-Q200 Thick Film | RESC0603 | R14 | RMCF0603FT42K2CT-ND | Digikey | 10
RMCF0603FT47K0 | 47 kOhms ±1% 0.1W, 1/10W Chip Resistor 0603 (1608 Metric) Automotive AEC-Q200 Thick Film | RESC0603 | R19, R21, R50, R52, R73, R76 | RMCF0603FT47K0CT-ND | Digikey | 10
RMCF0603FT52K3 | 52.3 kOhms ±1% 0.1W, 1/10W Chip Resistor 0603 (1608 Metric) Automotive AEC-Q200 Thick Film | RESC0603 | R64 | RMCF0603FT174KCT-ND | Digikey | 10
RMCF0603FT56R0 | 56 Ohms ±1% 0.1W, 1/10W Chip Resistor 0603 (1608 Metric) Automotive AEC-Q200 Thick Film | RESC0603 | R24, R25, R26, R27, R28 | RMCF0603FT56R0CT-ND | Digikey | 10
RMCF0603FT59K0 | 59 kOhms ±1% 0.1W, 1/10W Chip Resistor 0603 (1608 Metric) Automotive AEC-Q200 Thick Film | RESC0603 | R54, R60, R66 | RMCF0603FT59K0CT-ND | Digikey | 10
RMCF0603FT71K5 | 71.5 kOhms ±1% 0.1W, 1/10W Chip Resistor 0603 (1608 Metric) Automotive AEC-Q200 Thick Film | RESC0603 | R62 | RMCF0603FT71K5CT-ND | Digikey | 10
RMCF0603FT100K | 100 kOhms ±1% 0.1W, 1/10W Chip Resistor 0603 (1608 Metric) Automotive AEC-Q200 Thick Film | RESC0603 | R4, R8, R44, R45, R57, R59 | RMCF0603FT100KCT-ND | Digikey | 10
RMCF0603FT100R | 100 Ohms ±1% 0.1W, 1/10W Chip Resistor 0603 (1608 Metric) Automotive AEC-Q200 Thick Film | RESC0603 | R29, R30 | RMCF0603FT100RCT-ND | Digikey | 10
RMCF0603FT470K | 470 kOhms ±1% 0.1W, 1/10W Chip Resistor 0603 (1608 Metric) Automotive AEC-Q200 Thick Film | RESC0603 | R15, R16, R37, R46, R47, R56, R69, R70 | RMCF0603FT470KCT-ND | Digikey | 10
RMCF0603FT604K | 604 kOhms ±1% 0.1W, 1/10W Chip Resistor 0603 (1608 Metric) Automotive AEC-Q200 Thick Film | RESC0603 | R39 | RMCF0603FT604KCT-ND | Digikey | 10
RMCF0603FT750R | 750 Ohms ±1% 0.1W, 1/10W Chip Resistor 0603 (1608 Metric) Automotive AEC-Q200 Thick Film | RESC0603 | R13, R20 | RMCF0603FT750RCT-ND | Digikey | 10
RMCF0805FT120R | 120 Ohms ±1% 0.125W, 1/8W Chip Resistor 0805 (2012 Metric) Automotive AEC-Q200 Thick Film | RESC0805 | R42, R43 | 738-RMCF0805FT120RCT-ND | Digikey | 10
SF-1206SA500W-2 | Fuse Surface Mount 5A Slow Blow 50A Interrupt 1206 | SF-1206SA300W-2 | F1, F2, F3 | 118-SF-1206SA500W-2CT-ND | Digikey | 10
SLF12565T-101M1R6-PF | Inductor 100uH Shielded Drum Core, 1.9A 148mOhm | SLF12565T-101M1R6-PF | L1, L2 | 445-174227-1-ND | Digikey | 5
SMD22WS-TP | Diode Schottky 20V 2A Fast Recovery | SOD-323 | D1, D3 | SMD22WS-TPMSCT-ND | Digikey | 10
T2N7002AK,LM | N-Channel 60 V 200mA (Ta) 320mW (Ta) Surface Mount SOT-23-3 | SOT23-3 MOSFET | Q3, Q6, Q7 | T2N7002AKLMCT-ND | Digikey | 10
TLV1117-33IDCY | 3.3V 800-mA, 15-V, linear voltage regulator 4-SOT-223 -40 to 125 | TLV1117-33IDCY | U13 | 296-26777-5-ND | Digikey | 5
TPS62933DRLR | Buck Switching Regulator IC Positive Adjustable 0.8V 1 Output 3A SOT-583 | SOT-583 | U12 | 296-TPS62933DRLRCT-ND | Digikey | 5
TPS259474LRPWR | eFuse 5.5A, 2.7V~23V, 28mOhm, Reverse Current Blocking with Input Reverse Polarity Protection | VFQFN-10 | U5, U9, U17 | 296-TPS259474LRPWRCT-ND | Digikey | 10
TT6-10KC8-9-25 | NTC Thermistor 10k Probe | TT6-10KC8-9-25 | R11, R41 | 1912-TT6-10KC8-9-25-ND | Digikey | 2
WSLT2512R2000FEB | 200 mOhms ±1% 1W Chip Resistor 2512 (6332 Metric) Anti-Sulfur, Automotive AEC-Q200, Current Sense, Moisture Resistant, Pulse Withstanding Metal Element | WSLT2512R2000FEB | R12 | 541-10376-1-ND | Digikey | 5

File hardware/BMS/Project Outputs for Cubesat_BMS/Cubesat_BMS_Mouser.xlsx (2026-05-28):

Name | Description | Footprint | Designator | Distributor Part Number | Distributor | Quantity
BSC026N08NS5 | 80V N-Channel 23A (Ta), 100A (Tc) 2.5W (Ta), 156W (Tc) Surface Mount PG-TDSON-8-6 | PG-TDSON-8-5 | Q4, Q5 | 726-BSC026N08NS5ATMA | Mouser | 2
BZT52C12T-7 | Zener Diode 12 V 300 mW ±5% Surface Mount SOD-523 | SOD-523 | D7 | 621-BZT52C12T-7 | Mouser | 1
LVK12R050CER | Resistor, Current Sense 50 mOhms ±0.25% 0.5W, Moisture Resistant Thick Film | LVK12R050CER-1, LVK12R050CER-2 | R1, R5, R58, R68 | 588-LVK12R050CER | Mouser | 4
NTTFS5C454NLTAG | N-MOSFET 40 V , 85 A, 3.8 mΩ Rds(on) @ 10 V, WDFN-8 3.3×3.3 mm, low Qg (~18 nC) | NTTFS5C454NLTAG | Q1, Q2 | 863-NTTFS5C454NLTAG | Mouser | 2
STM32F446RET7 | ARM® Cortex®-M4 STM32F4 Microcontroller IC 32-Bit 180MHz 512KB (512K x 8) FLASH 64-LQFP (10x10) | LQFP-64 | U8 | 511-STM32F446RET7 | Mouser | 1

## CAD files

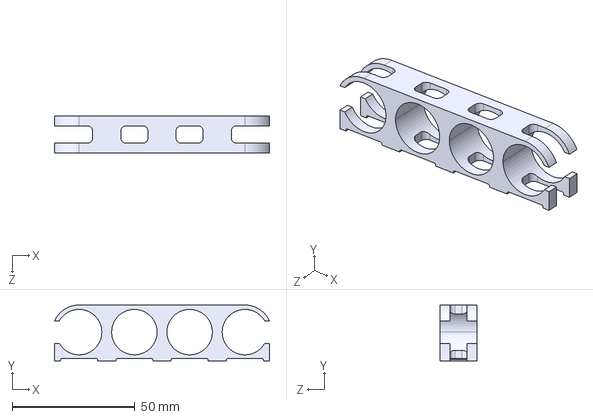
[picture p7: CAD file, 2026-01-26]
CAD/Top_Bracket.STEP
87.5 x 22.8 x 15.0 mm

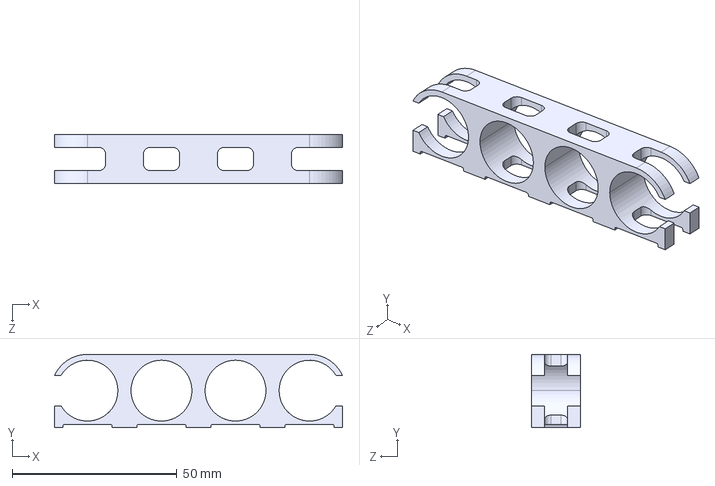
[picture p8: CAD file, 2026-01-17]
hardware/BMS/Top_Bracket.STEP
87.5 x 22.3 x 15.0 mm

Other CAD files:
CAD/Top_Bracket.SLDPRT.STEP
CAD/Top_Bracket.DWG
CAD/Top_Bracket.SLDDRW
CAD/Top_Bracket.SLDPRT

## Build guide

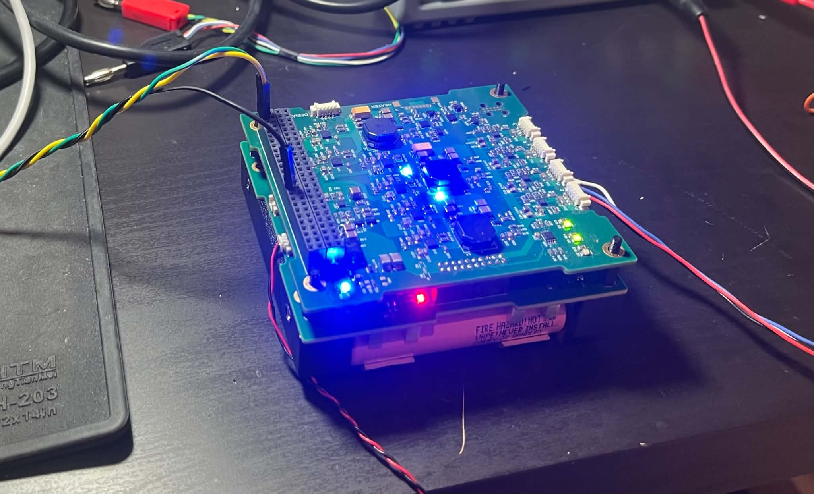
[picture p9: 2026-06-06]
Images/EPS_Assembly.jpg

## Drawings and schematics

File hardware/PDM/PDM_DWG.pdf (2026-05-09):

A

B

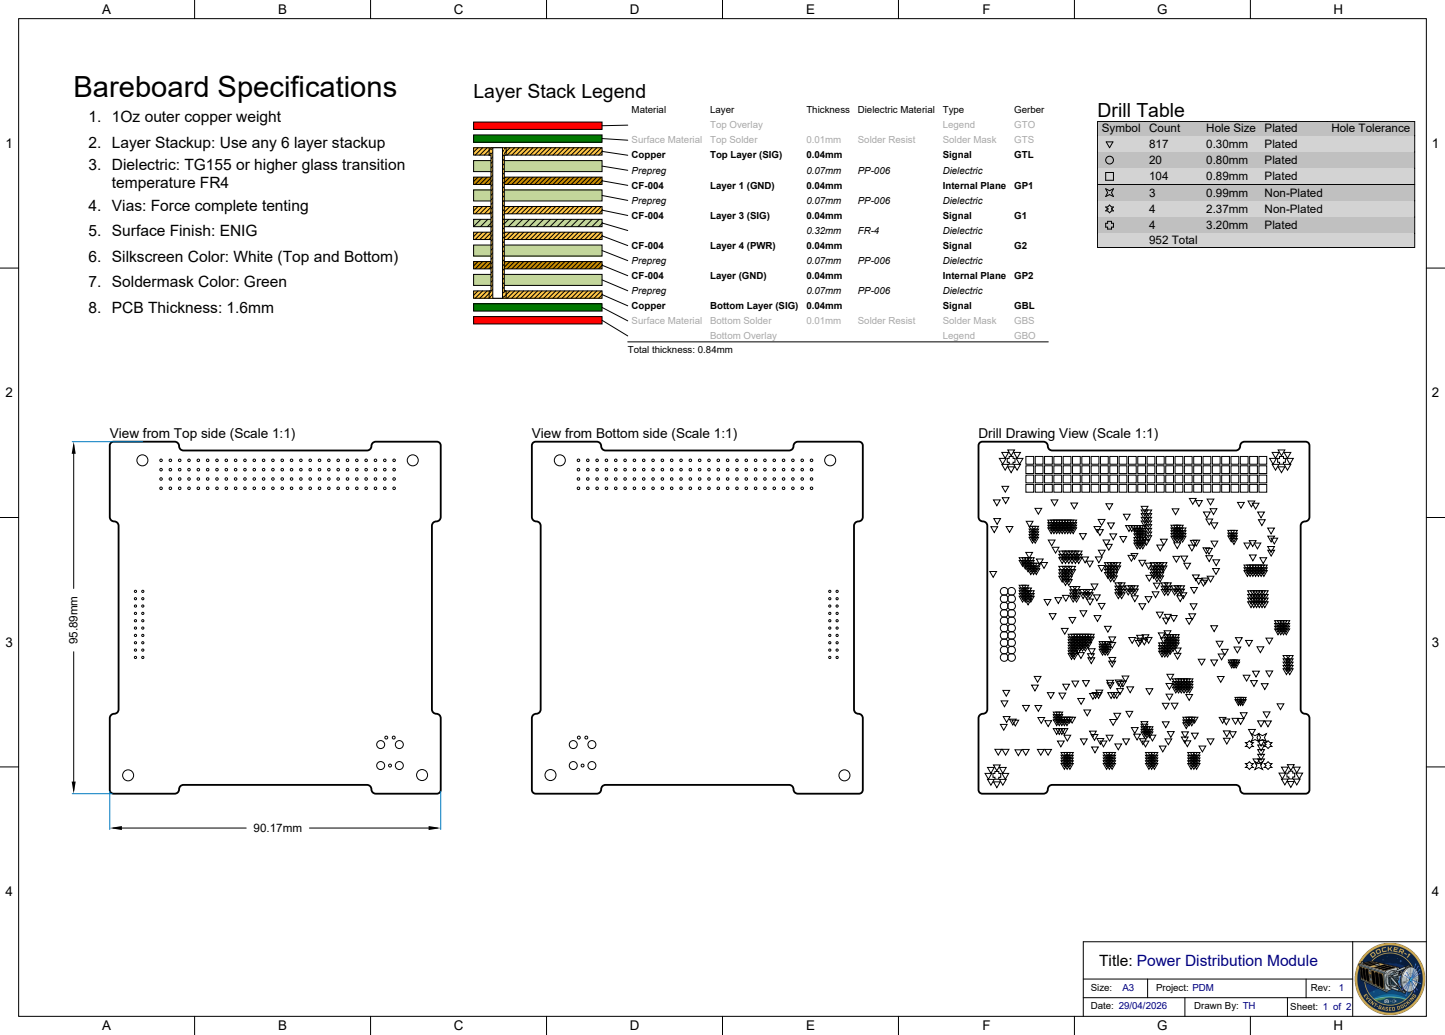
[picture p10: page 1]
View from Top side (Scale 1:1); View from Bottom side (Scale 1:1); Drill Drawing View (Scale 1:1); Size: A3; Project: PDM; Rev: 1; Date: 29/04/2026; Drawn By: TH; Sheet: 1 of 2; Material; Layer; Thickness Dielectric Material Type; Gerber; Drill Table; Top Overlay; Legend; GTO; Surface Material Top Solder; Solder Resist; Solder Mask; GTS; Copper; Top Layer (SIG); Signal; GTL; Prepreg; Dielectric; Layer 1 (GND); Internal Plane GP1; Layer 3 (SIG); Layer 4 (PWR); Layer (GND); Internal Plane GP2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

Layer Stack Legend

1. 1Oz outer copper weight
2. Layer Stackup: Use any 6 layer stackup
Dielectric: TG155 or higher glass transition
temperature FR4
4. Vias: Force complete tenting
5. Surface Finish: ENIG
6. Silkscreen Color: White (Top and Bottom)
7. Soldermask Color: Green
8. PCB Thickness: 1.6mm

Symbol | Count | Hole Size | Plated | Hole Tolerance

817 | 0.30mm | Plated
20 | 0.80mm | Plated
104 | 0.89mm | Plated
3 | 0.99mm | Non-Plated
4 | 2.37mm | Non-Plated
4 | 3.20mm | Plated
952 Total

Power Distribution Module
Title:

A

B

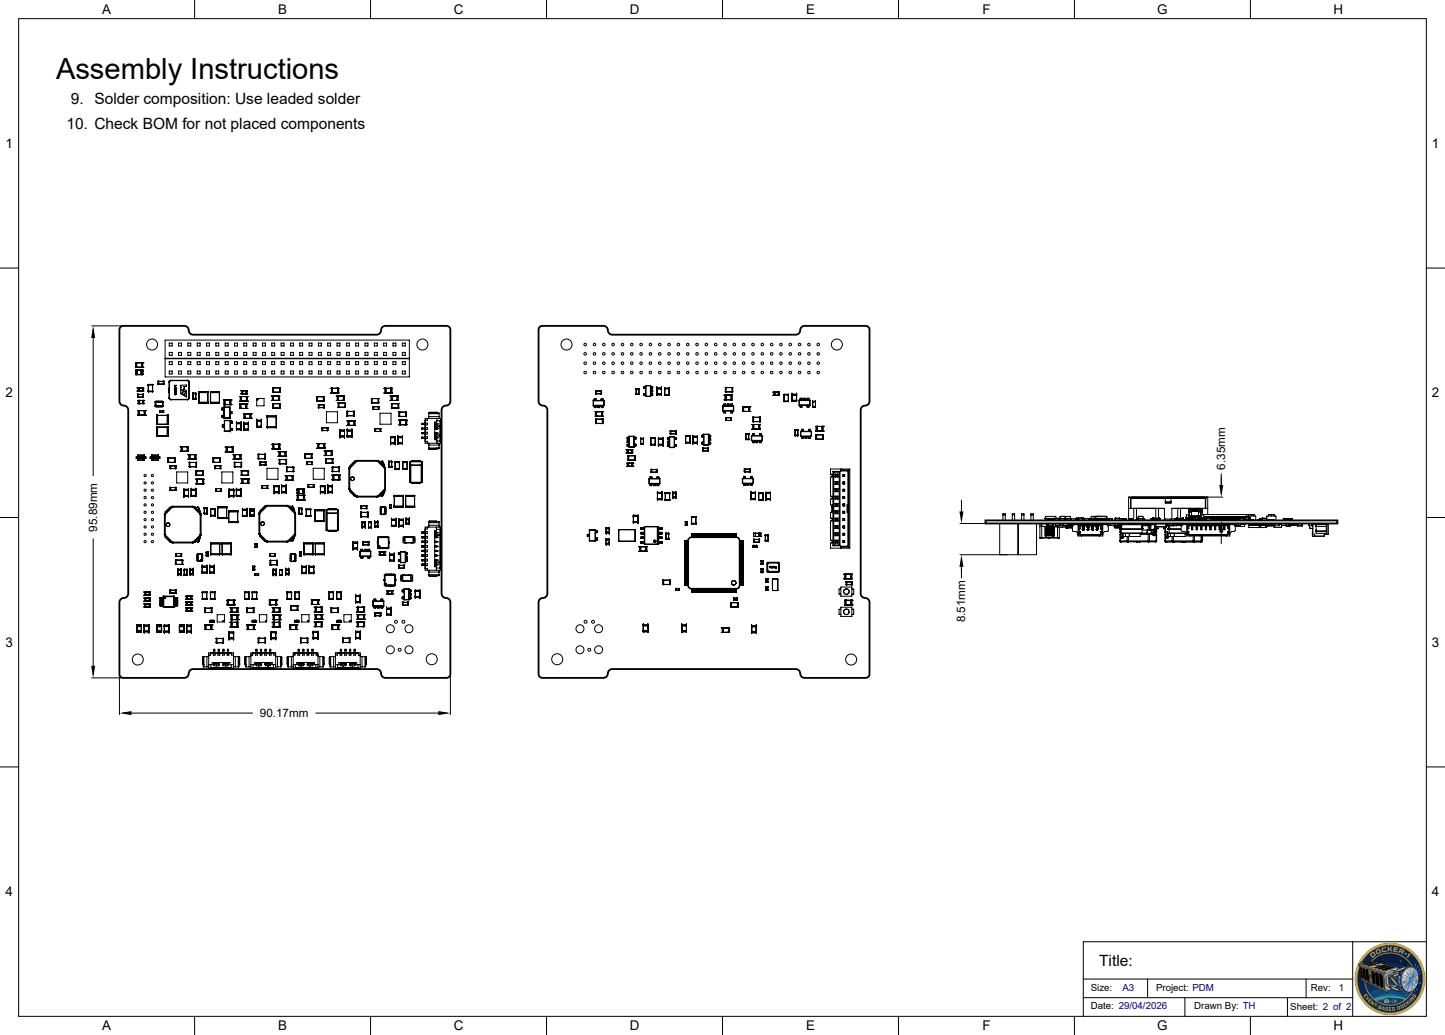
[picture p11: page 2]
Title:; Size: A3; Project: PDM; Rev: 1; Date: 29/04/2026; Drawn By: TH; Sheet: 2 of 2; Assembly Instructions 95.89mm

9. Solder composition: Use leaded solder
10. Check BOM for not placed components

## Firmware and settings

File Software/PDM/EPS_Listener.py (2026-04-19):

import json
import can
import time
import tkinter as tk
from tkinter import ttk
from dataclasses import dataclass

CONFIG_PATH = "conversions.json"

CAN_INTERFACE = "pcan"
CAN_CHANNEL = "PCAN_USBBUS1"
CAN_BITRATE = 125000

STALE_TIMEOUT_S = 2.0
REOPEN_DELAY_S = 0.5

EFUSE_BUTTONS = [
    ("3V3 CH2", 0x01),
    ("5V CH1",  0x02),
    ("5V CH2",  0x04),
    ("6V CH1",  0x08),
    ("12V CH1", 0x10),
    ("12V CH2", 0x20),
]

CONVERTER_BUTTONS = [
    ("5V Converter",  0x01),
    ("6V Converter",  0x02),
    ("12V Converter", 0x04),
]

EFUSE_STATUS_BITS = [
    ("3V3 CH2",  0x01),
    ("5V CH1",   0x02),
    ("5V CH2",   0x04),
    ("6V CH1",   0x08),
    ("6V CH2",   0x00),  # unused
    ("12V CH1",  0x10),
    ("12V CH2",  0x20),
]


@dataclass
class RegulatorTelemetry:
    name: str
    voltage: float
    currentCH1: float
    currentCH2: float


@dataclass
class BMSTelemetry:
    name: str
    battery_voltage: float
    battery_current: float
    sys_voltage: float
    battery_temp: float
    die_temp: float


@dataclass
class SystemTelemetry:
    name: str
    efuse_states_mask: int
    mcu_temp: float
    efuse_faults_mask: int


def load_config(path: str) -> dict:
    with open(path, "r") as f:
        return json.load(f)


def open_bus():
    return can.Bus(
        interface=CAN_INTERFACE,
        channel=CAN_CHANNEL,
        bitrate=CAN_BITRATE,
    )


def read_u16(data: bytes, offset: int) -> int:
    return (data[offset] << 8) | data[offset + 1]


def read_u8(data: bytes, offset: int) -> int:
    return data[offset]


def read_s16(data: bytes, offset: int) -> int:
    value = (data[offset] << 8) | data[offset + 1]
    if value & 0x8000:
        value -= 0x10000
    return value


def read_s8(data: bytes, offset: int) -> int:
    value = data[offset]
    if value & 0x80:
        value -= 0x100
    return value


def decode_regulator_telem(msg: can.Message, msg_cfg: dict) -> RegulatorTelemetry:
    signals = msg_cfg["signals"]

    raw_voltage = read_u16(msg.data, signals["rail_voltage"]["offset"])
    raw_currentCH1 = read_u16(msg.data, signals["current_ch1"]["offset"])
    raw_currentCH2 = read_u16(msg.data, signals["current_ch2"]["offset"])

    return RegulatorTelemetry(
        name=msg_cfg["name"],
        voltage=raw_voltage * signals["rail_voltage"]["scale"],
        currentCH1=raw_currentCH1 * signals["current_ch1"]["scale"],
        currentCH2=raw_currentCH2 * signals["current_ch2"]["scale"],
    )


def decode_bms_telem(msg: can.Message, msg_cfg: dict) -> BMSTelemetry:
    signals = msg_cfg["signals"]

    raw_battery_voltage = read_s16(msg.data, signals["battery_voltage"]["offset"])
    raw_battery_current = read_s16(msg.data, signals["battery_current"]["offset"])
    raw_sys_voltage = read_s16(msg.data, signals["sys_voltage"]["offset"])
    raw_battery_temp = read_s8(msg.data, signals["battery_temp"]["offset"])
    raw_die_temp = read_s8(msg.data, signals["die_temp"]["offset"])

    return BMSTelemetry(
        name=msg_cfg["name"],
        battery_voltage=raw_battery_voltage * signals["battery_voltage"]["scale"],
        battery_current=raw_battery_current * signals["battery_current"]["scale"],
        sys_voltage=raw_sys_voltage * signals["sys_voltage"]["scale"],
        battery_temp=raw_battery_temp * signals["battery_temp"]["scale"],
        die_temp=raw_die_temp * signals["die_temp"]["scale"],
    )


def decode_sys_telem(msg: can.Message, msg_cfg: dict) -> SystemTelemetry:
    signals = msg_cfg["signals"]

    efuse_states_mask = read_u8(msg.data, signals["efuse_states_mask"]["offset"])
    efuse_faults_mask = read_u8(msg.data, signals["efuse_faults_mask"]["offset"])

    raw_mcu_temp = read_u8(msg.data, signals["MCU_temp"]["offset"])
    mcu_temp = raw_mcu_temp * signals["MCU_temp"].get("scale", 1.0)

    return SystemTelemetry(
        name=msg_cfg["name"],
        efuse_states_mask=efuse_states_mask,
        mcu_temp=mcu_temp,
        efuse_faults_mask=efuse_faults_mask,
    )


def send_efuse_command(bus: can.Bus, enable_mask: int):
    msg = can.Message(
        arbitration_id=0x47,
        data=[enable_mask & 0xFF],
        is_extended_id=False,
    )
    bus.send(msg)


def send_converter_command(bus: can.Bus, enable_mask: int):
    msg = can.Message(
        arbitration_id=0x65,
        data=[enable_mask & 0xFF],
        is_extended_id=False,
    )
    bus.send(msg)


class TelemetryUI:
    def __init__(self, root: tk.Tk, config: dict, efuse_send_callback, converter_send_callback):
        self.root = root
        self.config = config
        self.efuse_send_callback = efuse_send_callback
        self.converter_send_callback = converter_send_callback

        self.root.title("EPS Telemetry Monitor")
        self.root.geometry("550x850")

        self.widgets = {}
        self.diag_widgets = {}
        self.status_var = tk.StringVar(value="Status: starting...")
        self.command_status_var = tk.StringVar(value="No command sent yet")

        notebook = ttk.Notebook(root)
        notebook.pack(fill="both", expand=True, padx=10, pady=10)

        self.telemetry_tab = ttk.Frame(notebook)
        self.command_tab = ttk.Frame(notebook)
        self.diagnostics_tab = ttk.Frame(notebook)

        notebook.add(self.telemetry_tab, text="Telemetry")
        notebook.add(self.command_tab, text="eFuse Control")
        notebook.add(self.diagnostics_tab, text="System Diagnostics")

        self._build_telemetry_tab()
        self._build_command_tab()
        self._build_diagnostics_tab()

    def _build_telemetry_tab(self):
        container = ttk.Frame(self.telemetry_tab, padding=10)
        container.pack(fill="both", expand=True)

        ttk.Label(container, textvariable=self.status_var).grid(
            row=0, column=0, sticky="w", pady=(0, 8)
        )

        row = 1
        for can_id, msg_cfg in self.config.items():
            msg_type = msg_cfg.get("type")
            name = msg_cfg.get("name", can_id)

            if msg_type not in ("regulator_telem", "BMS_telem"):
                continue

            frame = ttk.LabelFrame(container, text=name, padding=10)
            frame.grid(row=row, column=0, sticky="ew", pady=5)
            container.columnconfigure(0, weight=1)

            if msg_type == "regulator_telem":
                voltage_var = tk.StringVar(value="--- V")
                ch1_var = tk.StringVar(value="--- A")
                ch2_var = tk.StringVar(value="--- A")

                ttk.Label(frame, text="Voltage:").grid(row=0, column=0, sticky="w")
                ttk.Label(frame, textvariable=voltage_var).grid(row=0, column=1, sticky="w", padx=10)

                ttk.Label(frame, text="CH1 Current:").grid(row=1, column=0, sticky="w")
                ttk.Label(frame, textvariable=ch1_var).grid(row=1, column=1, sticky="w", padx=10)

                ttk.Label(frame, text="CH2 Current:").grid(row=2, column=0, sticky="w")
                ttk.Label(frame, textvariable=ch2_var).grid(row=2, column=1, sticky="w", padx=10)

                self.widgets[can_id] = {
                    "type": "regulator_telem",
                    "voltage": voltage_var,
                    "ch1": ch1_var,
                    "ch2": ch2_var,
                }

            elif msg_type == "BMS_telem":
                batt_voltage_var = tk.StringVar(value="--- V")
                batt_current_var = tk.StringVar(value="--- A")
                sys_voltage_var = tk.StringVar(value="--- V")
                batt_temp_var = tk.StringVar(value="--- °C")
                die_temp_var = tk.StringVar(value="--- °C")

                ttk.Label(frame, text="Battery Voltage:").grid(row=0, column=0, sticky="w")
                ttk.Label(frame, textvariable=batt_voltage_var).grid(row=0, column=1, sticky="w", padx=10)

                ttk.Label(frame, text="Battery Current:").grid(row=1, column=0, sticky="w")
                ttk.Label(frame, textvariable=batt_current_var).grid(row=1, column=1, sticky="w", padx=10)

                ttk.Label(frame, text="System Voltage:").grid(row=2, column=0, sticky="w")
                ttk.Label(frame, textvariable=sys_voltage_var).grid(row=2, column=1, sticky="w", padx=10)

                ttk.Label(frame, text="Battery Temp:").grid(row=3, column=0, sticky="w")
                ttk.Label(frame, textvariable=batt_temp_var).grid(row=3, column=1, sticky="w", padx=10)

                ttk.Label(frame, text="Die Temp:").grid(row=4, column=0, sticky="w")
                ttk.Label(frame, textvariable=die_temp_var).grid(row=4, column=1, sticky="w", padx=10)

                self.widgets[can_id] = {
                    "type": "BMS_telem",
                    "battery_voltage": batt_voltage_var,
                    "battery_current": batt_current_var,
                    "sys_voltage": sys_voltage_var,
                    "battery_temp": batt_temp_var,
                    "die_temp": die_temp_var,
                }

            row += 1

    def _build_command_tab(self):
        container = ttk.Frame(self.command_tab, padding=15)
        container.pack(fill="both", expand=True)

        ttk.Label(container, text="eFuse Controls").grid(
            row=0, column=0, columnspan=3, sticky="w", pady=(0, 10)
        )

        for i, (label, mask) in enumerate(EFUSE_BUTTONS):
            btn = ttk.Button(
                container,
                text=f"{label}\n0x{mask:02X}",
                command=lambda m=mask, l=label: self._send_efuse(m, l)
            )
            btn.grid(
                row=1 + i // 3,
                column=i % 3,
                padx=5,
                pady=5,
                sticky="nsew"
            )

        efuse_last_row = 1 + (len(EFUSE_BUTTONS) - 1) // 3

        converter_title_row = efuse_last_row + 2
        ttk.Label(container, text="Converter Controls").grid(
            row=converter_title_row, column=0, columnspan=3, sticky="w", pady=(15, 10)
        )

        for i, (label, mask) in enumerate(CONVERTER_BUTTONS):
            btn = ttk.Button(
                container,
                text=f"{label}\n0x{mask:02X}",
                command=lambda m=mask, l=label: self._send_converter(m, l)
            )
            btn.grid(
                row=converter_title_row + 1 + i // 3,
                column=i % 3,
                padx=5,
                pady=5,
                sticky="nsew"
            )

        for c in range(3):
            container.columnconfigure(c, weight=1)

        status_row = converter_title_row + 3
        ttk.Label(container, textvariable=self.command_status_var).grid(
            row=status_row, column=0, columnspan=3, sticky="w", pady=(15, 0)
        )

    def _build_diagnostics_tab(self):
        container = ttk.Frame(self.diagnostics_tab, padding=15)
        container.pack(fill="both", expand=True)

        title = ttk.Label(container, text="System Diagnostics")
        title.grid(row=0, column=0, columnspan=3, sticky="w", pady=(0, 12))

        mcu_temp_var = tk.StringVar(value="--- °C")
        ttk.Label(container, text="MCU Temperature:").grid(row=1, column=0, sticky="w", pady=(0, 10))
        ttk.Label(container, textvariable=mcu_temp_var).grid(row=1, column=1, sticky="w", pady=(0, 10))

        ttk.Label(container, text="eFuse States").grid(row=2, column=0, columnspan=3, sticky="w", pady=(10, 5))
        state_leds = {}

        state_start_row = 3
        for i, (label, mask) in enumerate(EFUSE_STATUS_BITS):
            row = state_start_row + i

            led = tk.Canvas(container, width=18, height=18, highlightthickness=0)
            led.grid(row=row, column=0, sticky="w", padx=(0, 8), pady=2)
            led_id = led.create_oval(2, 2, 16, 16, fill="red", outline="black")

            ttk.Label(container, text=label).grid(row=row, column=1, sticky="w", pady=2)

            state_leds[mask] = (led, led_id)

        fault_title_row = state_start_row + len(EFUSE_STATUS_BITS) + 1
        ttk.Label(container, text="eFuse Faults").grid(
            row=fault_title_row, column=0, columnspan=3, sticky="w", pady=(14, 5)
        )

        fault_leds = {}
        fault_start_row = fault_title_row + 1
        for i, (label, mask) in enumerate(EFUSE_STATUS_BITS):
            row = fault_start_row + i

            led = tk.Canvas(container, width=18, height=18, highlightthickness=0)
            led.grid(row=row, column=0, sticky="w", padx=(0, 8), pady=2)
            led_id = led.create_oval(2, 2, 16, 16, fill="green", outline="black")

            ttk.Label(container, text=label).grid(row=row, column=1, sticky="w", pady=2)

            fault_leds[mask] = (led, led_id)

        self.diag_widgets["sys_telem"] = {
            "mcu_temp": mcu_temp_var,
            "state_leds": state_leds,
            "fault_leds": fault_leds,
        }

    def _send_efuse(self, mask: int, label: str):
        try:
            self.efuse_send_callback(mask)
            self.command_status_var.set(f"Sent eFuse command: {label} -> 0x{mask:02X}")
        except Exception as e:
            self.command_status_var.set(f"eFuse send failed: {e}")

    def _send_converter(self, mask: int, label: str):
        try:
            self.converter_send_callback(mask)
            self.command_status_var.set(f"Sent converter command: {label} -> 0x{mask:02X}")
        except Exception as e:
            self.command_status_var.set(f"Converter send failed: {e}")

    def set_status(self, text: str):
        self.status_var.set(text)

    def update_regulator(self, can_id: str, reg: RegulatorTelemetry):
        if can_id not in self.widgets:
            return
        w = self.widgets[can_id]
        if w["type"] != "regulator_telem":
            return

        w["voltage"].set(f"{reg.voltage:.3f} V")
        w["ch1"].set(f"{reg.currentCH1:.3f} A")
        w["ch2"].set(f"{reg.currentCH2:.3f} A")

    def update_bms(self, can_id: str, bms: BMSTelemetry):
        if can_id not in self.widgets:
            return
        w = self.widgets[can_id]
        if w["type"] != "BMS_telem":
            return

        w["battery_voltage"].set(f"{bms.battery_voltage:.3f} V")
        w["battery_current"].set(f"{bms.battery_current:.3f} A")
        w["sys_voltage"].set(f"{bms.sys_voltage:.3f} V")
        w["battery_temp"].set(f"{bms.battery_temp:.1f} °C")
        w["die_temp"].set(f"{bms.die_temp:.1f} °C")

    def update_system(self, sys_telem: SystemTelemetry):
        if "sys_telem" not in self.diag_widgets:
            return

        w = self.diag_widgets["sys_telem"]

        w["mcu_temp"].set(f"{sys_telem.mcu_temp:.1f} °C")

        for mask, (canvas, led_id) in w["state_leds"].items():
            is_on = (sys_telem.efuse_states_mask & mask) != 0
            canvas.itemconfig(led_id, fill="green" if is_on else "red")

        for mask, (canvas, led_id) in w["fault_leds"].items():
            has_fault = (sys_telem.efuse_faults_mask & mask) != 0
            canvas.itemconfig(led_id, fill="red" if has_fault else "green")


class App:
    def __init__(self, root, config):
        self.root = root
        self.config = config
        self.bus = None
        self.last_rx_time = 0.0
        self.eFuseMasks = 0x00

        self.ui = TelemetryUI(
            root,
            config,
            self.send_efuse_command_wrapper,
            self.send_converter_command_wrapper
        )

        self.connect_bus()
        self.poll_can()

    def connect_bus(self):
        self.close_bus()
        try:
            self.bus = open_bus()
            self.last_rx_time = time.time()
            self.ui.set_status("Status: connected")
            print("CAN bus opened")
        except Exception as e:
            self.bus = None
            self.ui.set_status(f"Status: connect failed ({e})")
            print(f"Failed to open CAN bus: {e}")

    def close_bus(self):
        if self.bus is not None:
            try:
                self.bus.shutdown()
            except Exception:
                pass
            self.bus = None

    def reconnect_bus(self):
        self.ui.set_status("Status: reconnecting...")
        print("Reconnecting CAN bus...")
        self.close_bus()
        time.sleep(REOPEN_DELAY_S)
        self.connect_bus()

    def send_efuse_command_wrapper(self, mask: int):
        if self.bus is None:
            raise RuntimeError("CAN bus not connected")
        self.eFuseMasks ^= mask
        send_efuse_command(self.bus, self.eFuseMasks)
        print(f"Sent eFuse command: 0x{self.eFuseMasks:02X}")

    def send_converter_command_wrapper(self, mask: int):
        if self.bus is None:
            raise RuntimeError("CAN bus not connected")
        send_converter_command(self.bus, mask)
        print(f"Sent converter command: 0x{mask:02X}")

    def poll_can(self):
        try:
            if self.bus is None:
                self.connect_bus()
            else:
                msg = self.bus.recv(timeout=0.01)
                now = time.time()

                if msg is not None:
                    self.last_rx_time = now
                    can_id = f"0x{msg.arbitration_id:03X}"

                    if can_id in self.config:
                        msg_cfg = self.config[can_id]
                        msg_type = msg_cfg.get("type")

                        if msg_type == "regulator_telem":
                            reg = decode_regulator_telem(msg, msg_cfg)
                            self.ui.update_regulator(can_id, reg)

                        elif msg_type == "BMS_telem":
                            bms = decode_bms_telem(msg, msg_cfg)
                            self.ui.update_bms(can_id, bms)

                        elif msg_type == "sys_telem":
                            sys_telem = decode_sys_telem(msg, msg_cfg)
                            self.ui.update_system(sys_telem)

                        self.ui.set_status("Status: receiving")

                elif (now - self.last_rx_time) > STALE_TIMEOUT_S:
                    self.ui.set_status("Status: no frames, reopening adapter")
                    self.reconnect_bus()

        except Exception as e:
            print(f"CAN error: {e}")
            self.ui.set_status(f"Status: error ({e}), reopening")
            self.reconnect_bus()

        self.root.after(20, self.poll_can)

    def shutdown(self):
        self.close_bus()
        self.root.destroy()


def main():
    config = load_config(CONFIG_PATH)

    root = tk.Tk()
    app = App(root, config)

    root.protocol("WM_DELETE_WINDOW", app.shutdown)
    root.mainloop()


if __name__ == "__main__":
    main()

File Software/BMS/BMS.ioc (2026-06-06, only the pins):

Mcu.UserName=STM32F446RETx
PA0-WKUP.Signal=ADCx_IN0
PA1.Signal=ADCx_IN1
PA10.GPIO_Label=BMS_nSTAT
PA10.Signal=GPIO_Output
PA11.GPIO_Label=BMS_nQON
PA11.Signal=GPIO_Input
PA12.GPIO_Label=BMS_nINT
PA12.Signal=GPIO_Output
PA2.Signal=ADCx_IN2
PA3.Signal=ADCx_IN3
PA4.Signal=ADCx_IN4
PA5.Signal=ADCx_IN5
PA6.Signal=ADCx_IN6
PA7.Signal=ADCx_IN7
PA8.Signal=I2C3_SCL
PA9.GPIO_Label=BMS_nCE
PA9.Signal=GPIO_Input
PB0.Signal=ADCx_IN8
PB1.Signal=ADCx_IN9
PB10.GPIO_Label=BAT_PG
PB10.Signal=GPIO_Input
PB12.GPIO_Label=UMB_SHDN
PB12.Signal=GPIO_Output
PB13.GPIO_Label=UMB_PG
PB13.Signal=GPIO_Input
PB4.Signal=S_TIM3_CH1
PB5.Signal=S_TIM3_CH2
PB6.Signal=GPIO_Output
PB8.GPIO_Label=CHG_PG
PB8.Signal=GPIO_Input
PB9.GPIO_Label=CHG_SHDN
PB9.Signal=GPIO_Output
PC0.GPIO_Label=nACOK
PC0.Signal=GPIO_Input
PC1.GPIO_Label=nCHG_OK
PC1.Signal=GPIO_Input
PC2.GPIO_Label=nCHG_EN
PC2.Signal=GPIO_Output
PC5.GPIO_Label=BAT_SHDN
PC5.Signal=GPIO_Output
PC9.Signal=I2C3_SDA

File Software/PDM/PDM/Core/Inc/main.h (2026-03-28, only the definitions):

#define LED0_Pin GPIO_PIN_2
#define LED0_GPIO_Port GPIOE
#define BMS_nCE_Pin GPIO_PIN_3
#define BMS_nCE_GPIO_Port GPIOE
#define BMS_nQON_Pin GPIO_PIN_4
#define BMS_nQON_GPIO_Port GPIOE
#define BMS_nSTAT_Pin GPIO_PIN_5
#define BMS_nSTAT_GPIO_Port GPIOE
#define BMS_nINT_Pin GPIO_PIN_6
#define BMS_nINT_GPIO_Port GPIOE
#define _12V_CH2_IMON_Pin GPIO_PIN_0
#define _12V_CH2_IMON_GPIO_Port GPIOC
#define HEATER1_IMON_Pin GPIO_PIN_1
#define HEATER1_IMON_GPIO_Port GPIOC
#define HEATER2_IMON_Pin GPIO_PIN_2
#define HEATER2_IMON_GPIO_Port GPIOC
#define _5V5_VMON_Pin GPIO_PIN_0
#define _5V5_VMON_GPIO_Port GPIOA
#define _12V_VMON_Pin GPIO_PIN_1
#define _12V_VMON_GPIO_Port GPIOA
#define _12V_CH1_IMON_Pin GPIO_PIN_2
#define _12V_CH1_IMON_GPIO_Port GPIOA
#define _5V_CH1_IMON_Pin GPIO_PIN_3
#define _5V_CH1_IMON_GPIO_Port GPIOA
#define _6V_CH1_IMON_Pin GPIO_PIN_4
#define _6V_CH1_IMON_GPIO_Port GPIOA
#define _5V_CH2_IMON_Pin GPIO_PIN_5
#define _5V_CH2_IMON_GPIO_Port GPIOA
#define _3V3_CH2_IMON_Pin GPIO_PIN_6
#define _3V3_CH2_IMON_GPIO_Port GPIOA
#define _3V3_CH1_IMON_Pin GPIO_PIN_7
#define _3V3_CH1_IMON_GPIO_Port GPIOA
#define _5V_CH2_nFLT_Pin GPIO_PIN_4
#define _5V_CH2_nFLT_GPIO_Port GPIOC
#define _5V_CH2_EN_Pin GPIO_PIN_5
#define _5V_CH2_EN_GPIO_Port GPIOC
#define _3V3_VMON_Pin GPIO_PIN_0
#define _3V3_VMON_GPIO_Port GPIOB
#define _5V_VMON_Pin GPIO_PIN_1
#define _5V_VMON_GPIO_Port GPIOB
#define _6V_CONV_EN_Pin GPIO_PIN_2
#define _6V_CONV_EN_GPIO_Port GPIOB
#define _12V_CH2_nFLT_Pin GPIO_PIN_9
#define _12V_CH2_nFLT_GPIO_Port GPIOE
#define _12V_CH2_EN_Pin GPIO_PIN_10
#define _12V_CH2_EN_GPIO_Port GPIOE
#define _6V_CH1_EN_Pin GPIO_PIN_11
#define _6V_CH1_EN_GPIO_Port GPIOE
#define _6V_CH1_PG_Pin GPIO_PIN_12
#define _6V_CH1_PG_GPIO_Port GPIOE
#define _5V_CH1_nFLT_Pin GPIO_PIN_13
#define _5V_CH1_nFLT_GPIO_Port GPIOE
#define _5V_CH1_EN_Pin GPIO_PIN_14
#define _5V_CH1_EN_GPIO_Port GPIOE
#define _3V3_CH2_nFLT_Pin GPIO_PIN_8
#define _3V3_CH2_nFLT_GPIO_Port GPIOD
#define _3V3_CH2_EN_Pin GPIO_PIN_9
#define _3V3_CH2_EN_GPIO_Port GPIOD
#define _3V3_CH1_nFLT_Pin GPIO_PIN_10
#define _3V3_CH1_nFLT_GPIO_Port GPIOD
#define _3V3_CH1_EN_Pin GPIO_PIN_11
#define _3V3_CH1_EN_GPIO_Port GPIOD
#define CAN_SHDN_Pin GPIO_PIN_12
#define CAN_SHDN_GPIO_Port GPIOD
#define CAN_STB_Pin GPIO_PIN_13
#define CAN_STB_GPIO_Port GPIOD
#define _5V_CONV_EN_Pin GPIO_PIN_14
#define _5V_CONV_EN_GPIO_Port GPIOD
#define HEATER2_PWM_Pin GPIO_PIN_6
#define HEATER2_PWM_GPIO_Port GPIOC
#define HEATER1_PWM_Pin GPIO_PIN_7
#define HEATER1_PWM_GPIO_Port GPIOC
#define PANEL_PG3_Pin GPIO_PIN_15
#define PANEL_PG3_GPIO_Port GPIOA
#define PANEL_EN3_Pin GPIO_PIN_12
#define PANEL_EN3_GPIO_Port GPIOC
#define PANEL_PG2_Pin GPIO_PIN_0
#define PANEL_PG2_GPIO_Port GPIOD
#define PANEL_EN2_Pin GPIO_PIN_1
#define PANEL_EN2_GPIO_Port GPIOD
#define PANEL_PG1_Pin GPIO_PIN_2
#define PANEL_PG1_GPIO_Port GPIOD
#define PANEL_EN1_Pin GPIO_PIN_3
#define PANEL_EN1_GPIO_Port GPIOD
#define PANEL_EN0_Pin GPIO_PIN_4
#define PANEL_EN0_GPIO_Port GPIOD
#define PANEL_PG0_Pin GPIO_PIN_5
#define PANEL_PG0_GPIO_Port GPIOD
#define LED1_Pin GPIO_PIN_5
#define LED1_GPIO_Port GPIOB
#define BMS_SCL_Pin GPIO_PIN_6
#define BMS_SCL_GPIO_Port GPIOB
#define BMS_SDA_Pin GPIO_PIN_7
#define BMS_SDA_GPIO_Port GPIOB
#define _12V_CONV_EN_Pin GPIO_PIN_8
#define _12V_CONV_EN_GPIO_Port GPIOB
#define _12V_CH1_EN_Pin GPIO_PIN_0
#define _12V_CH1_EN_GPIO_Port GPIOE
#define _12V_CH1_nFLT_Pin GPIO_PIN_1
#define _12V_CH1_nFLT_GPIO_Port GPIOE

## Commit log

2026-01-17 add cad and software
    [Cubesat_BMS.PrjPcb, Power_Path.SchDoc, Seperation_Switches.SchDoc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]
2026-01-17 Add PDM
    [12V_Supply.SchDoc, 3V3_Supply.SchDoc, 3V3_eFuses.xlsm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]
2026-01-18 Change outline of bms
2026-01-18 Layout changes
    [Power_Path.SchDoc]
2026-01-18 Restart layout
    [12V_Supply.SchDoc, 3V3_Supply.SchDoc, 5V5_Supply.SchDoc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]
2026-01-22 Add Cell balancing and output eFuse
    [12V_Supply.SchDoc, 3V3_Supply.SchDoc, 5V5_Supply.SchDoc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]
2026-01-24 Finish layout again
    [Battery_Protection.SchDoc, Output_eFuse.SchDoc, Power_Path.SchDoc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]
2026-01-26 Finish bms project outputs
    [12V_Supply.SchDoc, 3V3_Supply.SchDoc, 5V5_Supply.SchDoc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]
2026-01-27 Change to JLC BOM but need to fix battery mosfets
    [BMS.GBL, BMS.GBO, BMS.GBP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]
2026-02-11 Small layout changes
    [BMS.GBL, BMS.GBO, BMS.GBP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]
2026-03-06 Push final board release
    [12V_Supply.SchDoc, 3V3_Supply.SchDoc, 5V5_Supply.SchDoc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]
2026-03-25 Start PDM software
    [5V5_Supply.SchDoc, 5V_Supply.SchDoc]
2026-03-25 eFuse switching from debug UART
    [Controller.SchDoc, PDM.SchDoc]
2026-03-28 analog working
    [Controller.SchDoc]
2026-04-10 Start CAN UI
    [12V_Supply.SchDoc, Controller.SchDoc, Ideal_Diode.SchDoc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]
2026-04-11 BMS software implemented
    [I2C_Buffer.SchDoc]
2026-04-28 add draftsman drawing
    [12V_Supply.SchDoc, 3V3_Supply.SchDoc, 5V5_Supply.SchDoc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]
2026-05-09 Implement watchdog
    [12V_Supply.SchDoc, 3V3_Supply.SchDoc, 5V5_Supply.SchDoc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]
2026-05-10 start bms rev 2
    [Battery_Protection.SchDoc, Battery_eFuse.SchDoc, Battery_eFuse_Calculation.xlsm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]
2026-05-12 Start layout
    [3V3_Supply.SchDoc, 5V_Supply.SchDoc, 6V_CH1_current_20260422_103122_servos.csv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]
2026-05-12 continue layout
    [Battery_Protection.SchDoc, Charger.SchDoc, Controller.SchDoc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]
2026-05-16 layout finished
    [Battery_Protection.SchDoc, Battery_eFuse.SchDoc, Controller.SchDoc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]
2026-05-16 finish bms layout
    [BMS.GBL, BMS.GBO, BMS.GBP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]
2026-05-16 recommit prj
    [Cubesat_BMS.PrjPcb]
2026-05-28 create project for new bms software
    [Battery_Protection.SchDoc, Battery_eFuse.SchDoc, Charger.SchDoc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]
2026-05-29 Implement charging power path
2026-05-30 add analog filtering
2026-05-31 begin i2c implementation on bms v2
    [Cubesat_BMS.PrjPcb]
2026-05-31 i2c telemetry implemented, not mapped correctly
    [Arduino_I2C_ttest.ino, BMS.ioc, bms.c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]
2026-05-31 Refactor bms code on pdm
2026-06-01 Fix op amp stability
    [Battery_Protection.SchDoc, MPPT.SchDoc, Power_Path.SchDoc]
2026-06-01 Neaten schematics for bms
    [Battery_Protection.SchDoc, Battery_eFuse.SchDoc, Charger.SchDoc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]
2026-06-03 Fix gpio output speed
    [BMS.ioc]
2026-06-06 Revise README to clarify project details and components
    Updated project description to specify Docker-1 CubeSat and detail the EPS components including BMS and PDM.
2026-06-06 Add EPS assembly image to readme
2026-06-06 Add eps assembly image
2026-06-06 Add BMS photos
2026-06-06 crop battery image
2026-06-06 Add more images of EPS in readme
    Added images of BMS PCB and Battery Pack to README.
2026-06-06 Add PDM images
    Added images and descriptions for PDM PCB views and updated battery pack image alt text.
2026-06-23 Add eps assembly files via upload
2026-06-23 Change eps assembly images
    Added images and descriptions for BMS PCB and Battery Pack.

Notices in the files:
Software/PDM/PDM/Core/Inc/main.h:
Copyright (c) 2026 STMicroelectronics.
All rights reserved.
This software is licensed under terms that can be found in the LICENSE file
